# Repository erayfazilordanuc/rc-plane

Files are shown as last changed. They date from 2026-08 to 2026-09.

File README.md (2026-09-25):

# ESP32 RC Plane

<p align="center">
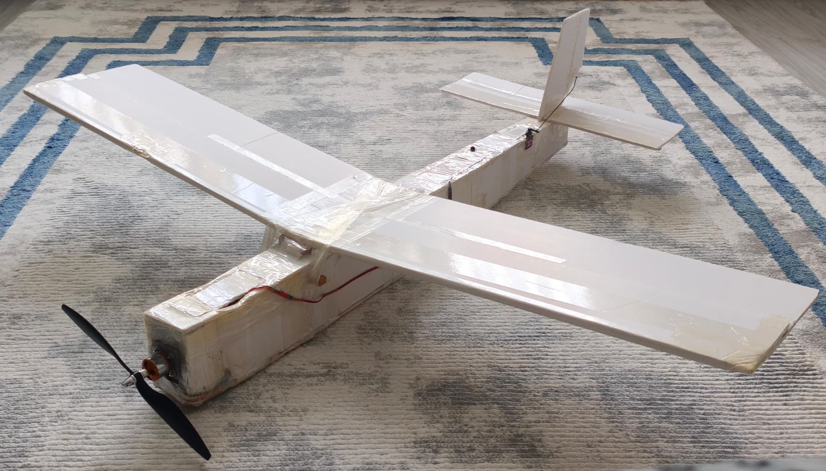
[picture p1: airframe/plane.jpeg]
The finished aircraft: white foam-board high-wing trainer with a green propeller, dihedral wing and conventional tail
  
</p>

A from-scratch radio control system and airframe. There is no hobby transmitter in this
project: an ESP32 ground station builds the RC frame itself from a phone's touch sticks,
and an ESP32 in the aircraft decodes it, drives the surfaces and reports back — over a
**redundant dual radio link** with failsafe logic on both ends. The airframe is a 1.4 m
foam-board trainer, designed on paper and cut by hand. It flies, but not for long: no launch
has lasted more than about ten seconds — [what the tests showed and what I got
wrong](#-flight-tests).

It started as a way around a ~5000 TL transmitter/receiver set. But once the ground station
*is* the transmitter, arming, failsafe and throttle limits become my problem rather than a
radio manufacturer's — so the interesting part is not that a servo moves, it is everything
that happens when the link degrades.

* **Two independent radios, one code path** — nRF24L01+ and ESP-NOW carry the same frame;
  either alone can fly the aircraft.
* **Safety enforced on both boards** — arm interlock, two-stage throttle ceiling, 500 ms
  failsafe, relink hysteresis, browser watchdog.
* **Phone as transmitter** — WebSocket touch gimbals with no app and no internet, servo
  calibration over the air, stored in the aircraft's flash.
* **Tested without hardware** — a Node harness checks the UI's maths against the firmware
  at 42 000 points before anything is flashed.

<p align="center">
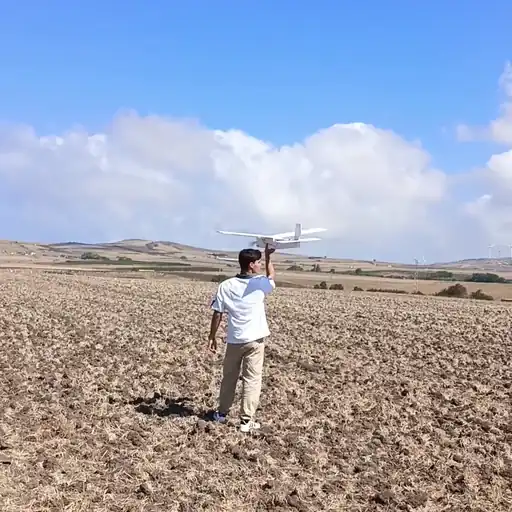
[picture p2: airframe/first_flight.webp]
Hand launch on a ploughed field: the aircraft leaves the hand under power, climbs away and flies across the field
  
  <br><sub>First field test, 21 September 2026 — hand launch and the first seconds of the flight.</sub>
</p>

## 📐 Mechanics

<p align="center">
  Airframe top, side and front views with dimensions: 1400 mm span, 200 mm chord, 1050 mm fuselage, CG 48 mm behind the leading edge
</p>

| | |
|---|---|
| **Construction** | 5 mm foam board, wooden spar, KFm-2 stepped airfoil, tape hinges |
| **Wing** | 1400 mm span, 200 mm constant chord, 28 dm², high wing, +1.4° incidence |
| **Control** | 3 channels — throttle, elevator, rudder; roll from rudder via 10° dihedral |
| **Tail** | 400 × 150 mm stabiliser (Vh 0.70), 180 mm fin (Vv 0.036) |
| **CG** | 278 mm from the firewall (measured): 48 mm behind the leading edge (24 %), just ahead of the spar |
| **Power** | A2212 1000 KV, 10×4.5 prop, 30 A ESC, 3S 2200 mAh 30C |
| **Weight** | 1106 g ready to fly, 39.5 g/dm² wing loading, thrust/weight ≈ 0.83 by eCalc (not measured) |

Tail volumes and CG are calculated, not guessed — thrust at flight speed was not, and that
is what the [flight tests](#-flight-tests) caught. Crashes are designed to be
cheap: the wing sits on **two dowels and rubber bands**, so a hard landing pops it off
instead of tearing the fuselage, and there is **no landing gear** — hand launch, belly
landing, sacrificial strip under the nose. The firewall and the ground station enclosure
are 3D-printed ([`cad/print_files/`](cad/print_files/)).

Every decision, the cut list, the weight budget and how the built aircraft differs from the
original plan: **[docs/AIRFRAME.md](docs/AIRFRAME.md)** (Turkish).

## 🔌 Electronics

```
┌──────────────────────────────┐            ┌──────────────────────────────┐
│  GROUND STATION (TX)         │            │  AIRCRAFT (RX)               │
│  WiFi AP ──► phone web UI    │  RcPacket  │  paketIsle()                 │
│  192.168.4.1   ┌──────────┐  │ ══ 50 Hz ═►│  ├─ verify (magic + CRC)     │
│                │ nRF24L01 │──┼─ 2.508 GHz │  ├─ arm interlock            │
│                └──────────┘  │            │  ├─ failsafe                 │
│                ┌──────────┐  │            │  └─ LEDC ──► ESC + 2 servos  │
│                │  ESP-NOW │──┼─ 2.412 GHz │                              │
│                └──────────┘  │◄═ telemetry│  RcTelemetry (8 B)           │
└──────────────────────────────┘            └──────────────────────────────┘
```

| | nRF24L01+ PA/LNA | ESP-NOW |
|---|---|---|
| Hardware | Separate module on VSPI, SMA antenna, `PA_HIGH` | **None** — the ESP32's own WiFi radio |
| Frequency | 2.508 GHz (channel 108) | 2.412 GHz (WiFi channel 1) |
| Addressing | `"RCP01"` pipe | Broadcast — no MAC pairing |
| Telemetry | ACK payload | Separate broadcast frame |

The 96 MHz gap is deliberate, so the access point cannot desensitise the nRF24. The
redundancy earned its place during bring-up: the nRF24 path was dead for a while (brown-out
on transmit, and a clone chip silently refusing 250 kbps) and ESP-NOW kept the aircraft
controllable while that was diagnosed.

### Ground station

<table>
<tr>
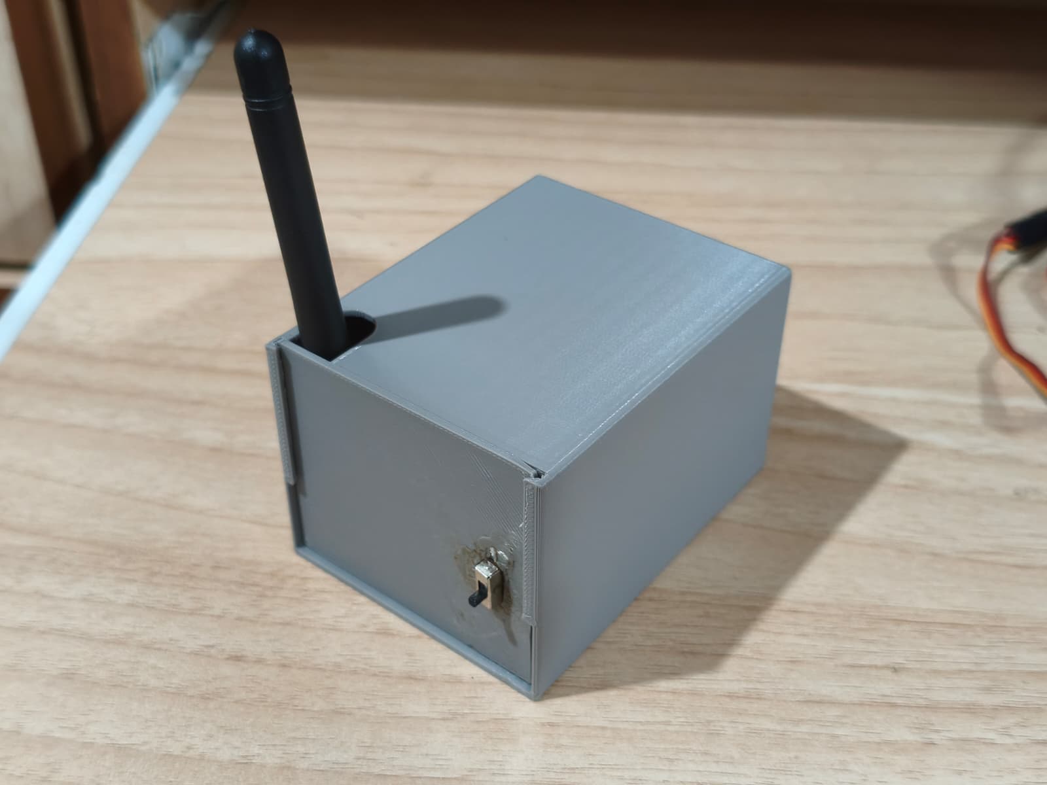
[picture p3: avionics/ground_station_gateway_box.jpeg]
Closed ground station: 3D-printed enclosure with antenna pass-through and power switch
<td width="50%"></td>
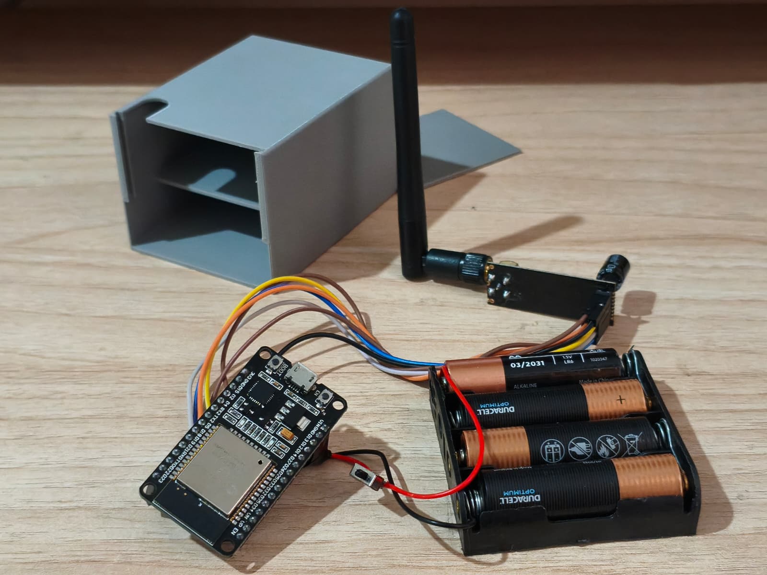
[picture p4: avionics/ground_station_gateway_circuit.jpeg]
Ground station opened up: ESP32-WROOM-32, nRF24L01+ PA/LNA with an SMA antenna, battery pack with a switch, next to its 3D-printed housing
<td width="50%"></td>
</tr>
</table>

The handheld transmitter: an ESP32-WROOM-32 and the nRF24 in a 3D-printed, 18650-powered
box. Runs the WiFi access point, the web server and the 50 Hz radio frame at once — the
dual core keeps HTTP work from stalling the frame. This board *is* the transmitter.

<p align="center">
  Ground station wiring diagram: nRF24L01+ on D23 MOSI, D19 MISO, D18 SCK, D5 CSN, D4 CE, 3V3 and GND with a capacitor at the module
</p>

Radio pins: SCK 18, MISO 19, MOSI 23, CSN 5, CE 4 — the same map as the aircraft, so a wiring
fix on one board is a wiring fix on the other.

### Avionics

<table>
<tr>
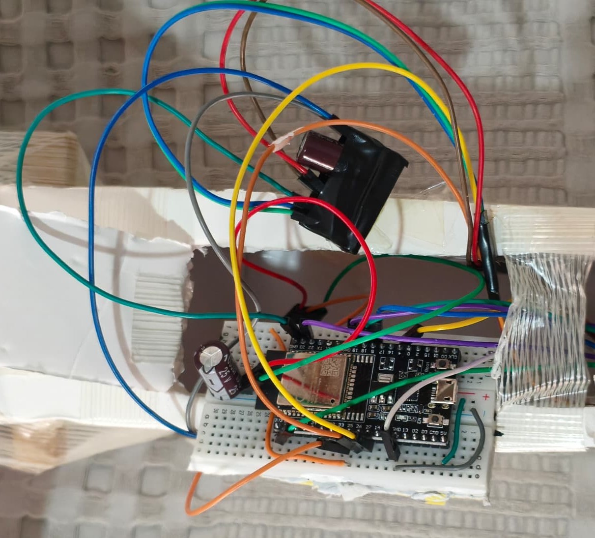
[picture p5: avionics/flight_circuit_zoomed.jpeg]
Electronics bay from above, installed in the fuselage: ESP32 DevKitC on a breadboard, nRF24 module wrapped in tape with its capacitor, wiring running out to the servos
<td width="50%"></td>
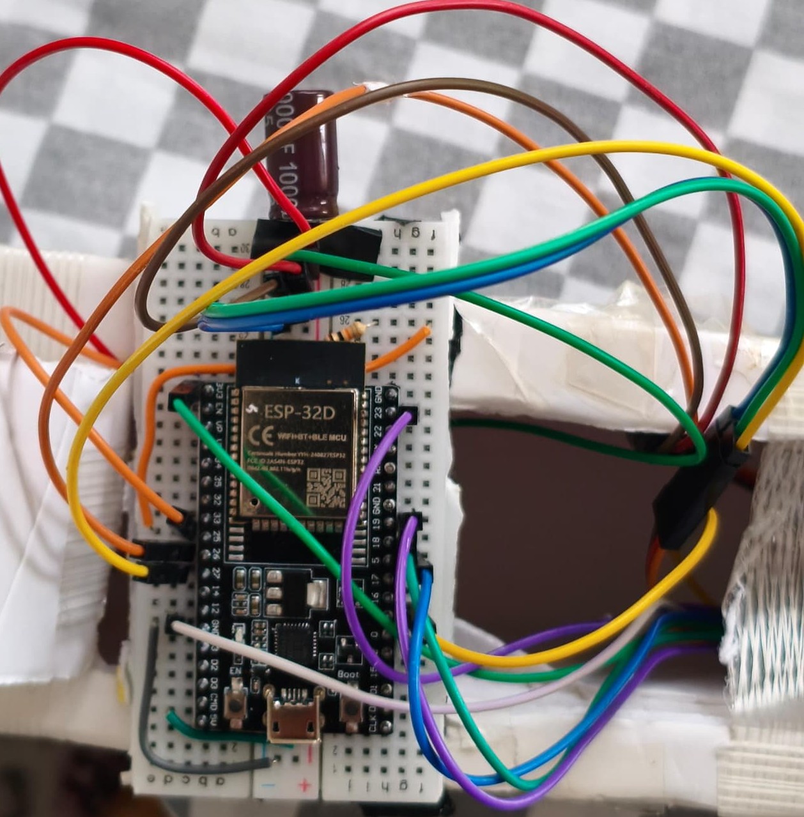
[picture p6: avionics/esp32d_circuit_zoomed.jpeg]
Close-up of the flight controller: ESP32-32D DevKitC on a breadboard with the bulk capacitor and jumper wires to the radio, ESC and servos
<td width="50%"></td>
</tr>
</table>

The flight controller: ESP32 DevKitC (WROOM-32D) inside the fuselage. Listens on both
radios, validates every frame, applies the stored calibration and drives the ESC and two
servos. Owns the failsafe, the arm lock and its own throttle ceiling, and sends telemetry
back.

**Power.** 3S LiPo → 30 A ESC → A2212, ≈ 15 A / 160 W at full throttle by eCalc. Moving the
servos used to crash the flight controller — first on the ESP32-C3 prototype, and again
after the move to the DevKitC. The cause was supply, not code: a 9 g servo pulls ~700 mA on
a step input, and the ESC's linear BEC, dropping 12 V to 5 V, could not hold the rail.
The fix was to disable that BEC and feed the board and servos from a **separate
5 V / 3 A UBEC** with a bulk capacitor across the rail; the crashes stopped. The boot log
prints the reset reason, so a returning `BROWNOUT` cannot hide.

<p align="center">
  Aircraft wiring diagram: ESC on GPIO25 with a 10k pull-down, elevator servo on GPIO26, rudder servo on GPIO27 through a servo rail; a separate 5 V UBEC feeds the rail and board with the ESC's BEC disabled; nRF24 on VSPI with a capacitor
</p>

| Function | GPIO |
|---|---|
| ESC signal | 25 *(10 k to GND)* |
| Elevator / Rudder | 26 / 27 |
| nRF24 SCK / MISO / MOSI | 18 / 19 / 23 |
| nRF24 CSN / CE | 5 / 4 |

Strapping pins (0, 2, 12, 15), the boot-pulsing GPIO 14 and the flash pins (6–11) are all
avoided; the 10 k keeps the ESC line quiet while the board boots. GPIO 32/33 carry mirrored
aileron outputs for a future 4-channel wing.

> ⚠️ **nRF24: 3.3 V only, and a 10–100 µF capacitor right at the module pins.** Without it
> the module browns out on transmit and `radio.begin()` succeeds only sometimes — the most
> misleading failure in this build. The firmware counts every radio recovery, so a
> brown-out cannot hide.

Cable-colour wiring tables: each firmware's `docs/kablolama.html` and
**[docs/RF_PROTOCOL.md](docs/RF_PROTOCOL.md)**. Diagrams are generated by
[`docs/diagrams/generate.py`](docs/diagrams/generate.py).

<details>
<summary>Earlier prototype: ESP32-C3 SuperMini on the bench</summary>
<br>
<p align="center">
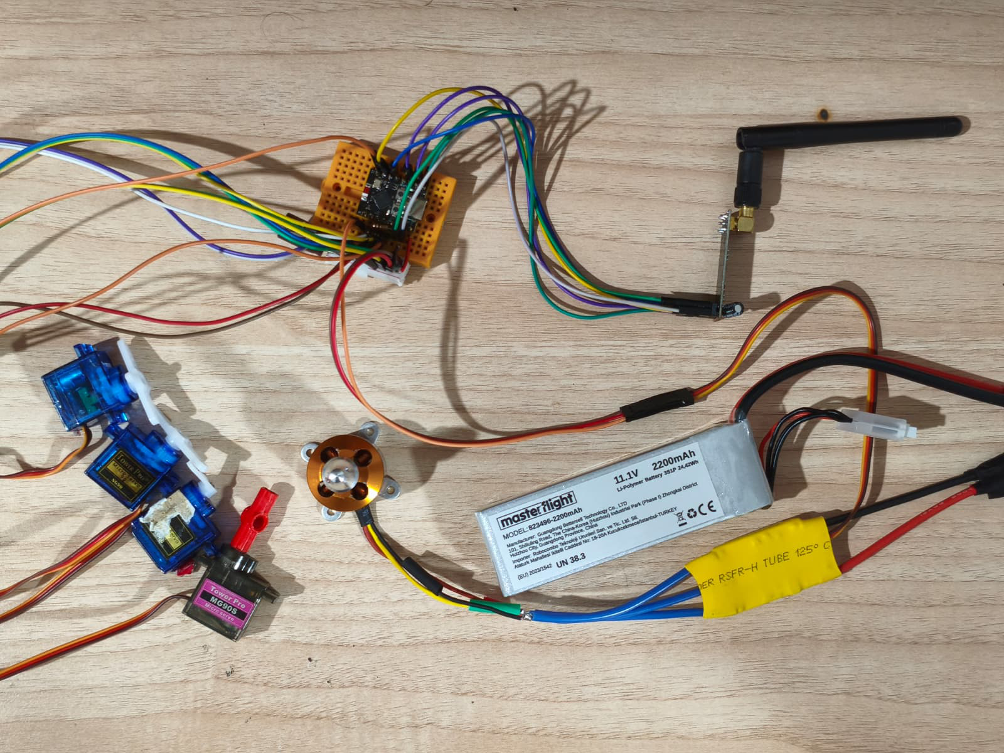
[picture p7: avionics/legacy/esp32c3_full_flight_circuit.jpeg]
Bench prototype: ESP32-C3 SuperMini on a mini breadboard, nRF24L01+ with antenna, 3S LiPo, ESC, A2212 motor and servos laid out on a desk
  
</p>
</details>

## 💻 Software

Two PlatformIO firmwares sharing one byte-identical protocol header (12-byte `RcPacket`,
CRC-8 on top of the nRF24's CRC-16, version nibble so mismatched firmware cannot half-work).

<p align="center">
  <picture>
    <source media="(prefers-color-scheme: dark)" srcset="docs/images/ui_3ch_dark.jpg">
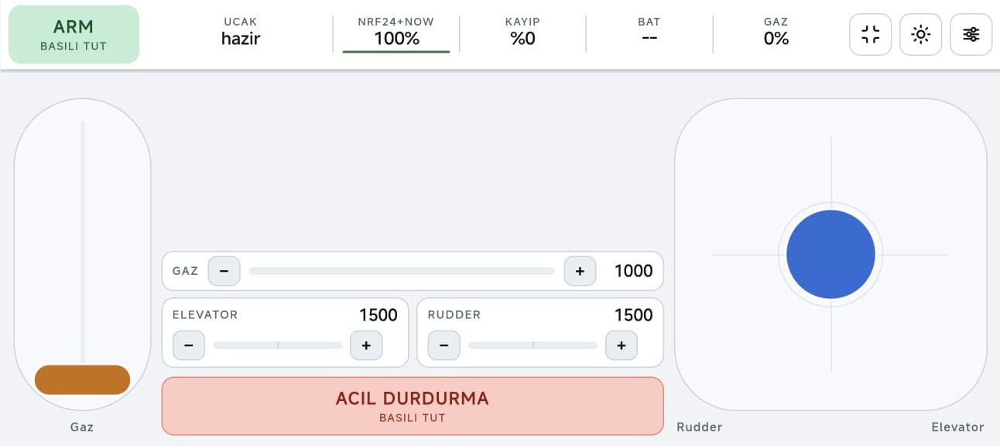
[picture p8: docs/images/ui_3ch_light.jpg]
Flight screen on a phone, 3 CH layout: throttle-only slot on the left, rudder and elevator gimbal on the right, ARM button and link, loss, battery and throttle readouts across the top, trim rockers and a hold-to-stop emergency button in the middle
    
  </picture>
  <br><sub>3 CH layout on the phone — aircraft ready, both radios up (<code>NRF24+NOW 100%</code>), no packet loss.</sub>
</p>

<details>
<summary>4-channel layout and the settings screen</summary>
<br>
<p align="center">
  <picture>
    <source media="(prefers-color-scheme: dark)" srcset="docs/images/ui_4ch_dark.jpg">
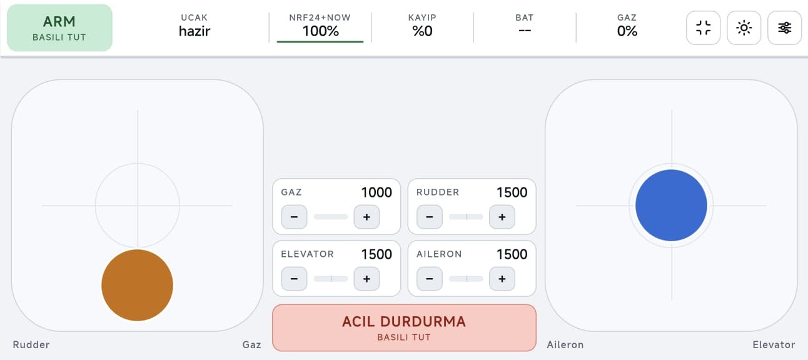
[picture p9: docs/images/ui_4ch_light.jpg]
Flight screen in 4-channel Mode 2: left gimbal rudder and throttle, right gimbal aileron and elevator, four trim rockers
    
  </picture>
  <br><sub>Mode 2 with ailerons enabled: two full gimbals, four trim rockers.</sub>
  <br><br>
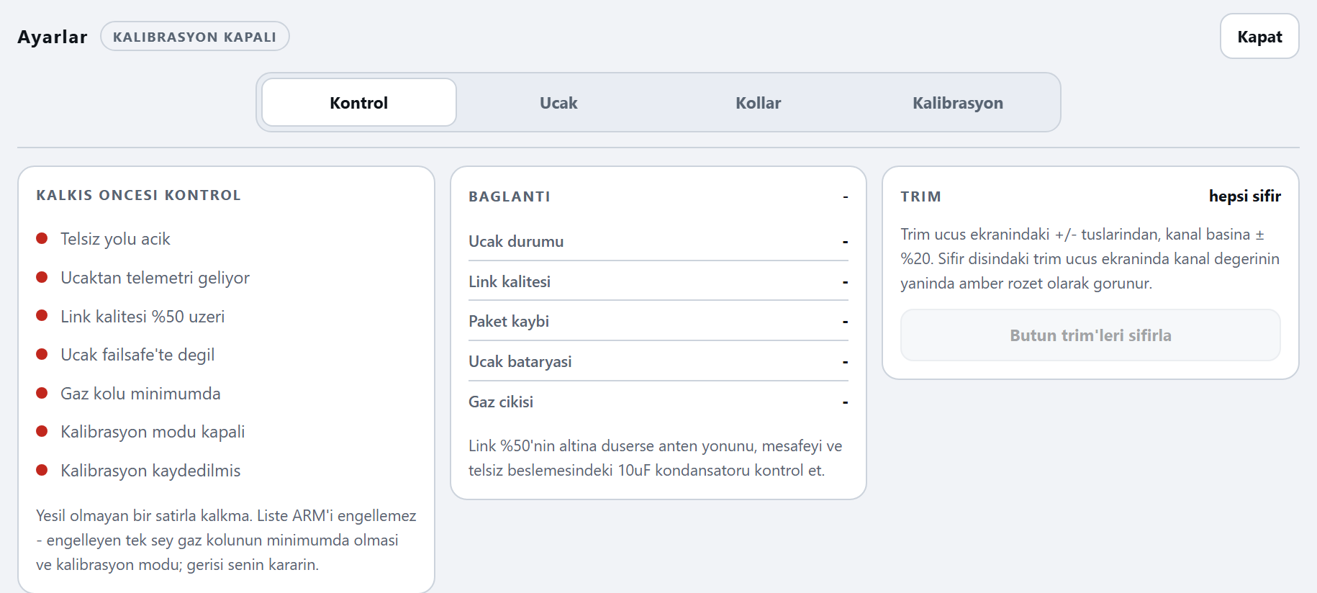
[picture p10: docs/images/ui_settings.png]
Settings screen: pre-flight checklist, link statistics and trim, with tabs for control, aircraft, sticks and calibration
  
  <br><sub>Settings, rendered from the firmware's own page with no aircraft connected — hence the red checklist.</sub>
</p>
</details>

### Safety — enforced independently on both boards

* **Arm interlock.** The aircraft boots locked and re-locks after every failsafe; it arms
  only after seeing `ARMED = 0` first, so a recovering link can never spin the motor.
* **Telemetry-gated arming.** The ground station will not arm without fresh telemetry —
  "controller says ARMED, aircraft never heard it" cannot happen.
* **Two-stage throttle ceiling.** Both sides clip against their own stored limit; the lower
  one wins. Set from the UI, no recompiling.
* **Failsafe.** 500 ms without a valid packet → ESC stop pulse, surfaces to *calibrated*
  neutral, arm dropped. Leaving it takes 10 consecutive good packets, so a twitching link
  doesn't stutter the motor.
* **Browser watchdog.** The 20 Hz stick push is the watchdog feed: close the tab or walk out
  of WiFi range and the ground station disarms within 1 s.
* **Duplicate suppression.** Both radios feed one `paketIsle()`; a packet seen twice is
  dropped by its `seq`, so outputs and telemetry are never doubled and the rules cannot drift
  apart between paths.

### Engineering notes

* **Direct LEDC servo output, no `ESP32Servo`** — microseconds end to end, same unit as the
  wire protocol. Runs at 14-bit resolution (~1.22 µs) because the C3 it started on silently
  fails at the 16 bits most examples use.
* **Non-blocking transmit** — `startWrite()` plus STATUS polling instead of `radio.write()`,
  which burns ~12 ms of the 20 ms frame when the link drops.
* **Broadcast telemetry, measured** — unicast gave `ack=0 / nack=57` and then
  `ESP_ERR_ESPNOW_NO_MEM`, because the aircraft is not associated with the AP. Broadcast
  needs no ACK; the payload carries its own magic byte and CRC.
* **Dependency-free WebSocket server** (`mini_ws.h`, SHA-1 and base64 included) —
  `WebServer` closes every connection, which made 20 Hz sticks jitter. Sends are gated by a
  zero-timeout `select()` so the flight loop never waits on a stalled socket.
* **Over-the-air servo calibration in NVS** — direction, sub-trim and per-side endpoints,
  retransmitted until acknowledged and read back from the aircraft, so the screen shows what
  was *applied*.
* **Honest sticks** — throttle engages only from the knob (no jumps), a finger sliding off
  the well freezes the value instead of tracking the edge, and every colour pair clears WCAG
  AAA for direct sun. USB gamepads work via the Gamepad API.
* **Self-healing radio** — `radio.begin()` retries every 3 s from a live register read, so a
  reseated wire recovers without a reset.

### Testing & diagnostics

```bash
cd firmware && node tools/run_all.mjs                       # UI harness, no hardware
cd controller_software && pio run -e rfdiag -t upload -t monitor   # raw-SPI nRF24 diagnosis
cd ../flight_software  && pio run -e bench  -t upload -t monitor   # servos/ESC from serial, no radio
```

The harness reads the firmware sources directly: stick maths, UI vs firmware throttle
formula at 42 000 points (the ARM threshold depends on it), the page's JavaScript against a
fake DOM, WCAG contrast in both themes, every `#id` present. `rfdiag` bypasses RF24 and
brute-forces all 12 pin-order combinations to find swapped wires.
[`sim_middleware`](firmware/sim_middleware/) is meant to turn the phone UI into a vJoy joystick
for simulator practice with the same controls — written, not yet tested against a simulator.

## Getting Started

**Needs:** [PlatformIO](https://platformio.org/) (RF24 is pulled automatically). Optional:
Node 24+ and Python 3.11 for the test harness.

```bash
git clone https://github.com/erayfazilordanuc/rc-plane.git
cd rc-plane/firmware/flight_software     && pio run -t upload -t monitor   # aircraft
cd ../controller_software                && pio run -t upload -t monitor   # ground station
```

Both `platformio.ini` files pin their serial port (`COM5` ground station, `COM6` aircraft)
because the two USB bridges look alike and PlatformIO would otherwise flash the wrong board.
Check yours with `pio device list`, one board at a time.

1. Power the ground station, join **`RC-Plane-TX`** / `rcplane1234` from a phone and open
   **`http://192.168.4.1`**.
2. Pick a layout — **Mode 1**, **Mode 2** (default) or **3 CH**. Elevator and rudder spring
   back; throttle stays put like a ratcheted stick.
3. **Settings → calibration:** set direction, neutral and endpoints per surface, sweep,
   **save to the aircraft**.
4. The pre-flight checklist shows exactly what is blocking ARM. **Remove the propeller for
   every bench test.**

Bench keys: `W`/`S` throttle, arrows elevator, `A`/`D` rudder, `Space` emergency stop,
`X` throttle cut.

```
airframe/  avionics/  cad/print_files/   photos, printable STLs
docs/       RF_PROTOCOL.md · AIRFRAME.md · ROADMAP.md (Turkish) · diagrams/ · images/
firmware/   controller_software/ · flight_software/ · tools/ · sim_middleware/
```

Per-firmware READMEs: **[ground station](firmware/controller_software/)** ·
**[aircraft](firmware/flight_software/)**. Deep-dives in `docs/` and source comments are in
Turkish.

## 🧪 Flight Tests

**What happened.** Hand launches from a ploughed field, first on **21 September 2026**, then
in a later session. The radio side worked every time; the airframe did not stay up. Every
launch was at full stick with default settings and a calibrated ESC — in the firmware that is
a 2000 µs pulse with nothing else limiting it (`gazUs()` on the ground station, `escYaz()`
on the aircraft).

| Launch | What the video shows (frame-counted) |
|---|---|
| Best, 21 Sep | Leaves the hand, climbs a little, then loses height slowly and cannot be held up — about ten seconds (clip at the top). The pilot's read: wind helped |
| Soft, nose-high | Released slow with the nose up, drops a wing, on the ground **1.2 s** after release |
| Lobbed upward | Thrown steeply up by the pilot, phone in the other hand; climbs a few metres, settles back, on the ground **~4.5 s** after release |

<p align="center">
  Two charts from a simple performance model at full throttle, for three possible static thrusts: about 912 g from eCalc, 650 g and 450 g. Left: thrust against drag versus airspeed; stall is about 8.5 m/s and at 450 g thrust never exceeds drag. Right: simulated hand launch from 2 m at 8.5 m/s; with a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
</p>

**What the model says.** A point-mass model, not a measurement —
[`flight_model.py`](docs/diagrams/flight_model.py), assumptions under the chart. Static thrust
comes from an eCalc run of this drive (below); how it falls off with speed comes from
Staples' propeller equation.

| | |
|---|---|
| Stall speed | ≈ 8.5 m/s |
| Minimum-drag speed | ≈ 8.4 m/s — the same as stall |
| Pitch speed, 10×4.5 | ≈ 16 m/s; at 10 m/s the prop gives 38 % of its static thrust |
| Full throttle, ≈ 912 g static (eCalc) | Level flight at 8.5–13.1 m/s, best climb ≈ 2.4 m/s |
| Static thrust below which height cannot be held | ≈ 440–500 g (thrust/weight 0.4–0.45) |

**Cross-check: eCalc.** I ran the same drive in [eCalc propCalc](https://www.ecalc.ch/)
(A2212 1000 KV, 10×4.5, 3S 2200 mAh 30C, 1105 g):

| | eCalc |
|---|---|
| Full throttle | 15.1 A, 10.5 V, 161 W, 8 680 rpm — 6.9 C on the pack, motor 82.5 % efficient |
| Static thrust | ≈ 912 g, thrust/weight 0.83 |
| Pitch speed | 60 km/h (16.7 m/s) |
| Stall / level speed | 30 km/h (8.3 m/s) / 68 km/h (18.9 m/s) |
| Rate of climb | 4.5 m/s |
| Flight time | 7.4 min at full throttle, 10.6 min mixed |

eCalc agrees on stall and pitch speed and is more optimistic than my model about the rest
(4.5 against 2.4 m/s climb). The conclusion doesn't depend on which is right: on paper,
this drive climbs.

* **Paper and field disagree — that is the finding.** With ≈ 912 g static both models
  climb away at full throttle. The aircraft didn't. The model reproduces the slow sink
  only if the motor makes less than ~500 g static, or if the wing is flying past its stall,
  where drag is far beyond this model (attached flow would need CD0 ≈ 0.3).
* **Power or speed?** The sink happens at low speed: the aircraft never gets clear of stall
  speed. What holds it there is the open question — too little thrust to accelerate, or a
  wing held at too high an angle (nose-high release, up elevator) that drags too much to
  accelerate. One measurement separates them: static thrust around 800 g or more clears the
  power train; around 500 g or less convicts it.
* **No speed margin.** Minimum-drag speed sits on top of stall speed, so anything that slows
  the aircraft — a soft throw, a nose-high release, pulling elevator to stop a sink — raises
  drag and deepens the sink. A 7 m/s throw starts below stall.
* **Wind — the best flight may have been luck.** Launched into a headwind, the aircraft
  leaves the hand with the throw *plus* the wind as airspeed, and a gust adds more for a
  moment. With stall and minimum-drag speed on top of each other, a lull is enough to drop it
  back into the sink. What wind can't do: a steady wind doesn't change airspeed once the
  aircraft is flying, and turning downwind costs groundspeed, not airspeed — only rising air
  holds a sinking aircraft up. Wind wasn't measured, so this stays a hypothesis.
* **It cannot glide out of trouble.** From 2 m with the motor off the model is on the ground
  in 1.6 s. Ten seconds in the air means the motor was pulling — without enough margin.

**What I got wrong.**
* Designed with static numbers — thrust/weight, tail volumes, CG — and never plotted thrust
  against drag at flight speed.
* Never measured the thrust. The 0.83 thrust/weight is eCalc's estimate, and "it rolls
  forward on the ground" only shows that thrust beats ground friction — a fraction of the
  weight.
* Weight grew 13 % (976 → 1106 g), wing loading 35 → 39.5 g/dm²; the margin was not
  re-checked.
* Launches were soft or nose-high, one of them one-handed.
* The docs recommend a 70–80 % throttle limit for first flights — wrong for this margin
  (the tests were flown at 100 %).
* Flew without data: no flight log, no fixed camera, no measured thrust, no wind reading.
  Every number above
  is a model until one of those exists.

**Proposed fixes, checked against the model.** An outside review of the first flights
suggested these:

| Proposal | Verdict |
|---|---|
| 9×6 prop instead of 10×4.5 | **Helps** — pitch speed 16 → 22 m/s, best climb 2.4 → 2.7 m/s (rpm assumed — to be run in eCalc). Check current draw |
| 1300–1500 mAh battery instead of 2200 | Small — about −80 g, stall −4 %; CG must be re-balanced |
| Rebuild at 750–800 g (bare foam or XPS) | **Biggest lever** — stall 7.0–7.2 m/s, wing loading 27–29 g/dm² |
| Clark Y / NACA 4412 instead of KFm-2 | Plausible, less drag; a new wing, so after the cheap fixes |
| Fin +15–20 % against spiral dives | **Not supported.** Vv 0.036 is within the usual 0.02–0.05. A bigger fin makes spiral divergence *more* likely, not less; strong dihedral with a small fin leans toward Dutch roll. Needs a stability analysis |
| Expo / deadband on the touch rudder | Expo is already there (25 % default); a deadband is not — cheap to add |

## Next Steps

### Without new parts

In this order — each result goes back into the model and this README.

1. **Static thrust** — tie the tail to a luggage scale anchored to a post, aircraft on a
   smooth floor, full throttle for a few seconds. Or stand it tail-down on a kitchen scale,
   held upright without pressing: weight minus reading = thrust. eCalc says ≈ 912 g.
2. **RPM and battery sag** — record the prop with [phyphox](https://phyphox.org/) (audio
   spectrum); RPM = blade-pass frequency × 30 for a two-blade prop, the model assumes
   ≈ 8 680. If a multimeter is at hand, read pack voltage at full throttle.
3. **Prop check** — size lettering and the curved face toward the front, nothing rubbing,
   air blown backwards. A prop mounted backwards loses much of its thrust.
4. **Launch drill** — full throttle before release, into the wind, wings level, nose on the
   horizon, a firm throw straight ahead. One person throws, the other flies. Don't pull while it sinks; let
   it gain speed.
5. **Fixed camera and wind** — tripod, side-on, 60 fps, two markers a known distance apart,
   a tape streamer on a stick in frame. [Tracker](https://physlets.org/tracker/) turns the clip
   into groundspeed and sink rate; with the wind, that is airspeed — the first measured numbers
   for the model. For 21 September, look up the hourly wind at the field in
   [Open-Meteo's historical data](https://open-meteo.com/en/docs/historical-weather-api).
6. **XFLR5** — model wing and tail in [XFLR5](http://www.xflr5.tech/) at Re ≈ 130 000: real
   polars instead of assumed drag and CL max, the static margin, and the dynamic modes
   (spiral, Dutch roll) that settle the fin question.
7. **eCalc, 9×6** — the 10×4.5 run is above; run 9×6 on the same drive for thrust, current
   and pitch speed before buying one.
8. **Simulator** — first check that [`sim_middleware`](firmware/sim_middleware/) works at all
   (untested). Then build this aircraft in RealFlight (1106 g, 1.4 m, 28 dm², 10×4.5,
   1000 KV) and practise launches.
9. **Flight log** — the ground station writes every frame to CSV, downloadable from the UI
   ([ROADMAP §4](docs/ROADMAP.md)).
10. **Rudder deadband** in the touch UI.

### Needs parts

* **9×6 prop** — more thrust at flying speed whatever step 1 shows.
* **Soldered board** — the electronics still sit on a breadboard inside the fuselage.
* **Battery telemetry** — `bataryaOku()` returns 0 today; needs a divider on an ADC1 pin.
* **Physical sticks** and **range testing** under real separation.
* **A lighter airframe** if the prop change is not enough.

Longer plan — link authentication, IMU stabilisation: **[docs/ROADMAP.md](docs/ROADMAP.md)**
(Turkish).

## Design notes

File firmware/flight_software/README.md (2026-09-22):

# Aircraft — `flight_software`

The airborne half of the RC Plane link. An **ESP32 DevKitC** (38-pin, ESP-WROOM-32 / 32D) listens on two radios at
once, validates every frame, runs it through a stored calibration curve, and drives the ESC
and two servos — with its own failsafe logic that does not trust the ground station.

**Three channels: throttle, elevator, rudder.** No ailerons — roll comes from rudder via
wing polyhedral, the classic 3-channel trainer layout. Which stick carries which surface is
a ground-station setting and does not reach this board: it always receives the same three
channels in the same order.

```
   nRF24 2.508 GHz  ═╗
                     ╠═► paketIsle() ─► magic + CRC-8 + version
   ESP-NOW 2.412 GHz ═╝        │        duplicate suppression
                               │        arm interlock
                               │        failsafe
                               ▼
                        calibration curve  ──► LEDC ──► ESC + 2 servos
                               │
                               └──► telemetry + calibration reports ──► ground
```

Either radio alone flies the aircraft. Both paths land in the same `paketIsle()`, so
validation, the arm lock and failsafe are defined exactly once.

---

## Wiring

Full diagram: [`docs/kablolama.html`](docs/kablolama.html) — open it in a browser.

| Function | GPIO | Note |
|---|---|---|
| **ESC signal** | **25** | 10 k from signal to GND — the pin floats during boot, the resistor keeps garbage out of the ESC |
| **Elevator servo** | **26** | |
| **Rudder servo** | **27** | |
| nRF24 SCK | 18 | VSPI |
| nRF24 MISO | 19 | VSPI |
| nRF24 MOSI | 23 | VSPI |
| nRF24 CSN | 5 | |
| nRF24 CE | 4 | |
| nRF24 VCC | 3V3 | top-left pin on the 38-pin board — **never 5 V** |

The radio uses the same five GPIOs as the ground station. GPIO 32/33 still carry the
mirrored aileron outputs in firmware; nothing is connected to them on this 3-channel airframe.

Avoided: **GPIO 0, 2, 12, 15** (strapping — a pulldown on GPIO0 drops the board into the
bootloader on every power-up, which is why the ESC moved off it), **14** (PWMs during boot),
**6–11** (internal flash, silkscreened `D0–D3`, `CMD`, `CLK` — `D2` is *not* GPIO2) and
**1/3** (UART0).

`SPI.begin(sck, miso, mosi, ss)` still names the pins explicitly, so a library that grabs SPI
first cannot move the radio. SPI runs at **4 MHz** — the same value the ground station
settled on, so the two cannot drift apart.

**Power.** The board and both servos run from a **separate 5 V / 3 A UBEC** on the flight
battery; the ESC's own linear BEC is disabled. A capacitor sits across 5 V–GND on that rail.
nRF24 on 3.3 V, with a 10 µF capacitor at its pins. Grounds common.

The boot log prints the reset reason. If you see `BROWNOUT` — especially *again* after
powering the motor — the problem is supply, not software: check the capacitor on the 5 V
rail and the ground first, then the UBEC's current rating and the wire gauge feeding it.

---

## Outputs

All three outputs are driven by the chip's LEDC peripheral directly. `ESP32Servo` is not
used, for two concrete reasons: its pin allowlist rejects GPIO0, and its degree↔µs
conversion shifted the neutral point. Writing duty directly means the firmware speaks the
same unit as the wire protocol — microseconds, end to end, no conversion anywhere.

> **The 14-bit C3 trap.** This firmware started on an ESP32-C3, whose LEDC timer maxes out at
> 14 bits, while nearly every example online uses 16 — valid on the classic ESP32. On the C3
> that made `ledcSetup()` silently return 0: no PWM at all, 0 V on the pin. Resolution stays
> at 14 bits so the code keeps working if the board ever goes back, and setup still checks
> the return value and shouts if it is zero. 14 bits @ 50 Hz gives ~1.22 µs resolution.
>
> On the classic ESP32 LEDC channels share timers in pairs (0–1, 2–3, 4–5). Every output
> here runs at 50 Hz / 14 bit, so sharing is harmless — an output at a different frequency
> needs its own pair, or `ledcSetup()` silently retunes its neighbour.

---

## Calibration

Servo direction, sub-trim and endpoints are **not** compile-time constants. They live in
this board's NVS (`rcplane`), set over the air from the ground station's settings screen.

That placement is deliberate: endpoints belong to the airframe's linkage geometry, not to
the pilot. They survive a reset, they can be changed with the receiver buried in a fuselage
and no USB attached, and — the part that actually matters — **failsafe neutral becomes the
calibrated neutral** rather than a hardcoded 1500 µs. If a linkage sits off-centre, so would
a hardcoded failsafe.

### The mapping

Standard **end point / travel adjust** behaviour, with independent scaling either side of
neutral:

```
input > 1500  →  scaled into  midUs .. maxUs
input < 1500  →  scaled into  minUs .. midUs
```

You can give one direction 100 % travel and the other 70 %; mechanical linkages are never
symmetric. Reversal happens *before* scaling, mirrored around neutral, so flipping direction
does not swap your endpoints.

Throttle reinterprets the same three fields: `minUs` is the ESC stop pulse, `maxUs` is full
throttle, and `midUs` is this aircraft's **own throttle ceiling** — independent of the
transmitter's limit, lower of the two wins.

### Why calibration cannot hurt the aircraft

| Guard | Where |
|---|---|
| Entering calibration is refused while armed | `RC_CFG_ENTER` |
| Arming is impossible while in calibration | `armed = ... && !kalibModu` |
| ESC pinned to its stop pulse for the whole mode | `escYaz()` |
| `TEST` and `SWEEP` never apply to the throttle output | `konfigIsle()` |
| Every write clamped to 900–2100 µs | `cikisYaz()` → `rcClampHard()` |
| Ordering and ≥50 µs of travel enforced before accepting | `ayarGecerli()` |
| `TEST` returns to neutral after 4 s | `kalibTick()` |
| Link loss exits calibration | `failsafeUygula()` |
| Corrupt NVS record falls back to factory values | `ayarYukle()` — signature + validation |

The `TEST` timeout matters more than it looks: a servo parked against a linkage stop draws
current and heats up. Every new `TEST` resets the timer, so the servo holds wherever you
want it while you drag a slider, and lets go when you walk away.

`SWEEP` runs a triangle wave min→max→min over 3 s, three times, then re-centres — enough to
hear a binding linkage before it strips a gear in the air.

**Throttle has no reverse.** Reversed throttle means full power with the stick down; the
setting that is useful on a control surface is a failure mode on a motor.

### ESC throttle range

An uncalibrated ESC can still read 1200 µs as stop — the usual cause of *"throttle is going
out but the motor won't turn"*. Two ways to teach it:

* **Serial** — press `k` within 5 s of boot, then confirm each step with `e`. The window
  opens on every boot (the classic ESP32 cannot tell whether USB is attached, unlike the C3's
  native USB), so a stray byte on the UART must never be enough to reach full throttle.
* **Over the air** — the settings screen, behind a prop-removed checkbox. This board also
  requires the `RC_CFGF_PROP_OFF` bit, calibration mode, and disarmed, then drops back to
  stop by itself after 30 s if step 2 never arrives.

Both routines deliberately exceed the throttle ceiling, which is why neither is reachable
from flight code. **Remove the propeller.**

---

## Failsafe and the arm chain

| Condition | Result |
|---|---|
| No valid frame for 500 ms | ESC to stop, surfaces to **calibrated** neutral, disarmed, arm lock re-armed |
| Bad magic / CRC / protocol version | Frame dropped silently, consecutive-valid counter reset |
| Link returns | **10 consecutive** valid frames required before leaving failsafe |
| Boot, and after every failsafe | **Arm-locked** — will not arm until it has seen a frame with `ARMED = 0` |

The arm lock is the piece worth explaining. A recovering link must never spin the motor on
its own, so the lock only releases when the ground station explicitly reports disarmed —
meaning the operator has to cycle DISARM → ARM by hand.

The relink hysteresis exists because recovering on a single frame made the motor stutter
every time the link twitched.

> **Ground station state ≠ aircraft state.** The interface shows both. If the transmitter
> says ARMED while this board says DISARM, the arm lock has not released — press DISARM and
> ARM again.

---

## Telemetry

An 8-byte frame carrying battery millivolts, packet loss, `rxHz`, and status bits (armed /
failsafe / calibration / unsaved-config). It rides the nRF24 ACK payload and goes out as an
ESP-NOW broadcast, **and refreshes every 100 ms independently of packet arrival**.

That independence is not decoration. The ground station refuses to arm without fresh
telemetry, and duplicate-suppression gaps would otherwise read as *"the aircraft is not
answering"*.

`rxHz` counts unique frames per second. Link quality as a percentage never answered "how
many frames actually arrived"; at 50 Hz you expect 50, and any shortfall is visible directly.

In calibration mode the same return path alternates telemetry with configuration reports,
cycling through all three outputs at about 5 Hz. Each report carries the value **actually
being written** to that output — so the settings screen shows what the aircraft applied, not
what was sent to it.

Battery measurement is stubbed at `0`, which the interface renders as `--`. Add a divider to
an **ADC1** pin (GPIO 32–39, e.g. 35 — ADC2 is unusable while ESP-NOW holds the radio) and
fill in `bataryaOku()`; the gauge starts working on its own.

---

## Build & flash

```bash
pio run -t upload -t monitor
```

`platformio.ini` pins **COM6** explicitly. That number belonged to the old C3's native USB;
the DevKitC enumerates through its USB bridge and may get another one — run
`pio device list` with only this board attached and update both environments. Without a
pinned port PlatformIO takes the first one it finds — COM5, the ground station — and flashes
the wrong board.

Roughly 58 % of the app partition, 13 % of RAM.

### Bench testing

```bash
pio run -e bench -t upload -t monitor    # no radio at all
pio run -t upload -t monitor             # back to flight firmware
```

[`hardware_test/servo_bench_ledc.cpp`](hardware_test/servo_bench_ledc.cpp) drives the
outputs from the serial port with no radio involved, which splits "is the software wrong" from
"is it power, ground or wiring". If the servos move here, the software and pin mapping are
fine.

It also carries two diagnostics for hand-soldered boards, where the silkscreen number and
the actual GPIO do not always agree:

* `t` — pulls every candidate pin to 3.3 V DC at once. Every wire you soldered should read
  3.3 V at its far end; 0 V means it is not on the board, or it is a cold joint.
* `p` — walks the candidates one at a time and prints which pin it is driving, so you can
  find which GPIO a mystery wire actually lands on.
* `v` — 50 % duty on the selected servo pin for 5 s. A normal servo pulse is 5–10 % duty and
  reads 0.16–0.33 V on a cheap multimeter, indistinguishable from nothing. 50 % reads
  ~1.65 V and leaves no doubt.

**Disconnect the ESC, servos and nRF24 for `t` and `p`, and power the board from USB** — they
drive plain 3.3 V DC, and pushing that into a line tied to 5 V damages the chip.

`hardware_test/hardware_test.ino` is an Arduino IDE archive of the same idea, kept only for
a quick try. Nothing builds it; the LEDC version above supersedes it.

### Reading the log

```
[RX] nrf=BAGLI now=BAGLI | DISARM rxarm=0 kilit=ACIK relink=0/10 |
     thr=1000<-1000(disarm) ele=1500->1500 rud=1500->1500 |
     50 paket, tekrar 50, kayip %0, bozuk 0 | tlm nrf=50/red0 now=50/hata0
```

| Field | Meaning |
|---|---|
| `rxarm` | The raw ARMED bit as received |
| `kilit` | Arm lock. `KAPALI` means ARMED is ignored no matter what arrives |
| `thr=A<-B(reason)` | A applied, B requested, and why it was clipped |
| `ele=A->B` | A received, B written after the calibration curve |
| `tekrar` | Copies arriving via the second radio — normal, not loss |

*"Throttle is going out but the motor won't turn"* with `thr=1000<-1600(disarm)` in the log
means the problem is the arm gate, not the transmitter.

`tekrar` sitting near the unique-frame count is what a healthy redundant link looks like:
every frame arrived twice, and the second copy was discarded before it touched an output.

---

## Layout

```
src/main.cpp                        radios, safety chain, calibration, LEDC outputs, NVS
include/rc_protocol.h                wire format — byte-identical copy in controller_software
hardware_test/servo_bench_ledc.cpp   bench test + solder diagnostics (separate environment)
hardware_test/hardware_test.ino      Arduino IDE archive, not built
docs/kablolama.html                  wiring diagram, open in a browser
```

Protocol details: [`docs/RF_PROTOCOL.md`](https://github.com/erayfazilordanuc/rc-plane/blob/main/docs/RF_PROTOCOL.md).

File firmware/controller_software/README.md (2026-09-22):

# Ground Station — `controller_software`

The transmitter half of the RC Plane link. An **ESP32-WROOM-32** raises its own WiFi
access point, serves a phone flight interface, and pushes a 10-byte RC frame to the
aircraft **50 times a second** over two independent radios.

There is no commercial transmitter in this project. This board *is* the transmitter.

```
        phone (browser)                    this board                        air
   ┌────────────────────────┐      ┌──────────────────────────┐
   │  two touch gimbals     │  WS  │  expo · dual rate · trim │   nRF24 2.508 GHz
   │  bottom corners        │ ═══► │  arm interlocks          │ ═══════════════════►
   │  sends on touch event  │ :81  │  50 Hz frame builder     │   ESP-NOW 2.412 GHz
   └────────────────────────┘      └──────────────────────────┘ ◄═══ telemetry ═════
      RC-Plane-TX / 192.168.4.1            ESP32-WROOM-32
```

---

## What it does

| | |
|---|---|
| **WiFi AP** | `RC-Plane-TX` / `rcplane1234`, channel 1, one client, `http://192.168.4.1` |
| **Interface** | Single page, ~39 KB, served straight from PROGMEM. No SD card, no upload step |
| **Uplink** | `RcPacket` (10 B) at 50 Hz over nRF24 **and** ESP-NOW simultaneously |
| **Downlink** | Telemetry (8 B) and calibration reports (13 B), from either radio |
| **Stored on board** | Pilot settings — stick mode, trim, expo, dual rate, throttle limit |

Protocol details live in [`docs/RF_PROTOCOL.md`](https://github.com/erayfazilordanuc/rc-plane/blob/main/docs/RF_PROTOCOL.md). The wire format
itself is in [`include/rc_protocol.h`](include/rc_protocol.h), which must stay **byte-identical**
to the copy in `flight_software`.

---

## Wiring

nRF24L01+ on VSPI. `SPI.begin()` names the pins explicitly — partly as documentation,
partly to override any library that grabbed SPI first.

| nRF24L01 | ESP32 | Wire colour |
|---|---|---|
| VCC | **3V3** — never 5 V | red |
| GND | GND | black |
| CE | GPIO4 | blue |
| CSN | GPIO5 | magenta |
| SCK | GPIO18 | orange |
| MOSI | GPIO23 | cyan |
| MISO | GPIO19 | green |
| IRQ | not connected | — |

SPI runs at **4 MHz**, not the library's 10 MHz default — dupont wire and breadboard are
not reliable at 10 MHz.

> **A 10–100 µF capacitor across VCC–GND, as close to the module pins as possible, is not
> optional.** The module draws a current spike on transmit; without the cap it browns out
> and `radio.begin()` succeeds only sometimes. That intermittency is the single most
> misleading failure in this build.
>
> The header is 2×4 with **GND on pin 1 and VCC on pin 2**. Being one row off reverses the
> supply and kills the module. Touch it after powering up — if it is warm, pull it.

---

## The interface

Designed as an instrument panel, not a web page. Landscape, gimbals in the **bottom
corners**, at least 140 dp on a side (`clamp(140px, min(34vw,46vh), 300px)`).

**Three stick layouts.** A 3-channel airframe has no ailerons, so one horizontal axis is
always spare — what changes between modes is *where* the spare axis sits. It is drawn
locked and greyed rather than left looking broken.

| | Left stick | Right stick |
|---|---|---|
| **Mode 1** | rudder + elevator | throttle |
| **Mode 2** *(default)* | rudder + throttle | elevator |
| **3 CH** | throttle only | rudder + elevator |

Mode 2 is the simulator and world standard. **3 CH** is the layout you get on a real radio
by assigning rudder to the aileron channel and gathering both surfaces on the right stick,
which leaves the left stick as a pure throttle lever — a common preference on 3-channel
trainers. The mode is stored on the board, so it survives a phone change.

Elevator and rudder spring back to centre on release. Throttle stays where you left it,
like a ratcheted stick.

### Anchored sticks: touching is not a command

The moment a finger lands, the stick's *current* value is anchored to that point. What moves
a channel is the motion **after** touchdown — where in the well you landed is irrelevant.

Absolute mapping came first, and it had two faults. The obvious one: grabbing a stick meant
hitting its exact centre, and missing made the stick **jump** to wherever the finger landed.
The one that matters in the air: a hand brushing the well threw a surface to full deflection
instantly.

Anchoring removes both. A knock only sets a reference point; nothing moves.

**Origin push** is the known trap of this model and its fix. With a fixed reference you could
not grab near the top of the well and keep pulling up, so full deflection was unreachable in
one gesture. When the limit is hit the *base value* shifts instead, keeping the finger
meaningful: full deflection is reachable from any grab point, and pulling back responds
**immediately** rather than sticking at saturation. The well border turns amber at full
deflection.

**Scale:** 100 px of finger travel is half a channel's width. Surfaces run centre-to-edge for
full deflection, throttle bottom-to-top for 0→100 % — the same total travel either way, like a
physical gimbal. Lifting and re-grabbing accumulates.

Multi-touch is per gimbal via pointer capture, so *released* and *dragged outside* never get
confused and both sticks work at once. A second finger in the same well is ignored.

### Guarding against knocks

A hand will hit the screen mid-flight. The decisions:

| Risk | Decision |
|---|---|
| A knock throws a surface | Anchored sticks — touching changes nothing |
| Palm and thumb in one well | Second `pointerId` in that well is ignored |
| Touch outside the wells | Drives no channel at all |
| ARM / emergency hit by accident | **Press-and-hold** (600 ms / 400 ms); sliding 44 px cancels |
| Settings opening over the sticks | AYAR is locked while armed |
| Back gesture, long-press menu | Swallowed (`popstate`, `contextmenu`) |
| Accidental reload | Browser confirms while armed (`beforeunload`) |
| System edge gesture reaching a stick | Wells sit 16 px in from the edge |
| URL bar and edge swipes | Fullscreen + landscape lock attempted on first touch |

Requiring a hold on the emergency stop is deliberate: a stray finger cutting the motor into a
forced landing costs far more than 400 ms does in a real emergency.

**Stick data is sent on the touch event itself**, not on a timer — 10 ms floor only so a
120 Hz digitiser cannot flood the socket, plus a 50 ms keepalive that doubles as the
watchdog feed. The interface adds no buffering of its own; end-to-end latency is
essentially the radio's own 20 ms frame.

Also on the flight screen: a pre-arm checklist that names whatever is blocking ARM, live
link / packet-loss / battery / throttle readouts, in-flight trim rockers, and a large
failsafe banner that never covers the sticks.

**Deliberately absent from the flight screen:** animation, transitions, gradients, shadows.
Every colour pair on it clears WCAG AAA against its background, so it stays readable in
direct sun. `navigator.vibrate()` marks arm, disarm and failsafe; a screen Wake Lock keeps
the display on, and pulling down the notification shade does not disturb a single channel.

A USB gamepad works too, through the Gamepad API. Keyboard, for bench work: `W`/`S`
throttle, arrows elevator, `A`/`D` rudder, `Space` emergency stop, `X` throttle cut.

---

## Safety

Every guard here is duplicated independently on the aircraft. Trusting one side alone means
a corrupted packet or a stale browser tab can spin a propeller.

| Condition | Result |
|---|---|
| Boot | Always disarmed |
| Throttle **output** above 1020 µs | ARM refused — checks the pulse, not the stick, so positive throttle trim cannot sneak past |
| No fresh telemetry from the aircraft | ARM refused, and auto-disarm after 1 s |
| Aircraft in calibration mode | ARM refused; auto-disarm if it enters one |
| Browser silent for 1 s | Auto-disarm, surfaces neutral |
| Disarmed | Throttle channel forced to 1000 µs on the wire |
| Emergency button / `Space` | Immediate disarm, all channels neutral |

`TEZGAH_MODU` (bench mode) relaxes only the telemetry requirement, for diagnosing a broken
downlink on the bench. **It ships as `false`.** When true it shouts about it in the boot log,
in every `[TX]` line, and across the top of the interface.

---

## Stick feel

Applied on this board, not in the browser, so a different phone cannot lose your trim.
Stored in NVS under `rctx`.

| Setting | Range | Default |
|---|---|---|
| Stick mode | 1 / 2 / 3 (3 CH) | 2 |
| Trim — throttle / elevator / rudder | ±200 µs (**±20 %** of channel width) | 0 |
| Expo — elevator / rudder | 0–50 % | 25 |
| Dual rate — elevator / rudder | 30–100 % | 100 |
| Throttle limit | 20–100 % | 100 |

Expo uses the industry-standard curve `y = x·((1−e) + e·x²)`: it softens the middle without
giving up any authority at the endpoints. 25 % keeps a first flight from feeling twitchy.

Throttle is limited twice — once here, once against the aircraft's own stored ceiling. The
two are independent and the lower one wins.

Servo direction, sub-trim and endpoints are **not** here. Those belong to the airframe and
live in the aircraft's flash; this board just drives the calibration screen.

---

## How it works

* **A dependency-free WebSocket server** — [`include/mini_ws.h`](include/mini_ws.h), SHA-1 and
  base64 included. `WebServer` stamps `Connection: close` on every response, so 20 Hz stick
  updates meant a fresh TCP handshake per frame and visibly jittery surfaces. A flight-ready
  firmware also should not need the internet to compile, which ruled out pulling in a
  library. The handshake accumulates across `loop()` passes and never blocks.

* **Sends are gated behind a zero-timeout `select()`.** `WiFiClient::write()` retries a
  stalled socket ten times with a one-second timeout each — up to ~10 s of blocking. The
  flight loop must never be the thing that waits, and a skipped status frame costs nothing.

* **Non-blocking radio transmit.** `startWrite()` plus STATUS polling instead of
  `radio.write()`, which blocks until ACK or until all retries are exhausted — about 12 ms
  of a 20 ms budget when the link drops, i.e. the controller gets sluggish exactly when
  control matters most. A transmit over 15 ms is aborted and the FIFO flushed; the count
  shows up as `takilan=N`.

* **Broadcast telemetry, and why not unicast.** Unicast was tried and measured out:
  `ack=0 / nack=57` — not one of 57 sends per second acknowledged, then
  `ESP_ERR_ESPNOW_NO_MEM`. The aircraft's STA is not associated with this AP, so its unicast
  frames get no MAC-layer ACK; ESP-NOW retries, the queue fills, telemetry stops completely.
  Broadcast frames expect no ACK and never fill the queue, and the payload carries its own
  magic byte and CRC-8.

* **Calibration commands are retransmitted** every 60 ms until the aircraft echoes the
  matching sequence number, giving up at 1500 ms with a visible error. A config frame takes
  its own 20 ms slot; skipping one control frame is harmless, losing a `SAVE` is not.

* **Self-healing radio.** `radio.begin()` is retried every 3 s and link state comes from a
  live register read, so a wire reseated mid-session recovers without a reset.

* **HTTP fallback stays wired.** If the WebSocket cannot be established the page falls back
  to polling `/c`, and the calibration screen keeps working through `/status`.

---

## Build & flash

```bash
pio run -t upload -t monitor
```

`platformio.ini` pins **COM5** (the CP210x bridge on this board) explicitly. Without it
PlatformIO takes the first port it finds and flashes the aircraft instead. Check yours with
`pio device list`.

The default environment builds only the flight firmware, so a bare `pio run -t upload` can
never leave the diagnostic image on the board.

Roughly 65 % of the app partition, 14 % of RAM.

### Diagnostics

```bash
pio run -e rfdiag -t upload -t monitor      # raw-SPI nRF24 diagnosis
pio run -t upload -t monitor                # back to the transmitter
```

[`diag/rf_diag.cpp`](diag/rf_diag.cpp) bypasses the RF24 library entirely and drives SPI by
hand: shorts, MISO drive, all 12 SCK/MISO/MOSI and CE/CSN permutations, then a speed sweep.
It reports the correct wiring order if the wires got swapped. **It does not bring up WiFi.**

If the registers it reads are bit-shifted copies of each other — `0x08, 0x10, 0x21, 0x42,
0x84` — the MISO line is floating and the module is not answering at all.

### Reading the log

```
[TX] nrf=BAGLI now=BAGLI ws=VAR | web=20/s | kumanda=DISARM ucak=DISARM
     thr=1000 ele=1500 rud=1500 | link=98% | rx=OK 50Hz kayip=%0 vbat=0mV
```

`web=0/s` means the problem is the browser, not the radio — the page is not sending.
`ws=yok` means the WebSocket never came up and the HTTP fallback is carrying control.

---

## Layout

```
src/main.cpp            radio, safety chain, HTTP + WebSocket endpoints, NVS
include/rc_protocol.h    wire format — byte-identical copy in flight_software
include/mini_ws.h        WebSocket server, no external dependency
include/web_ui.h         the phone interface, one PROGMEM string
diag/rf_diag.cpp         raw-SPI nRF24 diagnosis (separate environment)
```

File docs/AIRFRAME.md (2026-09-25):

# RC Plane — Mekanik Tasarım Kararları

3 kanallı (gaz, elevator, rudder) eğitim uçağı. 5 mm fotobloktan elde kesildi.
Aileron yok: yatış, kanadın dihedral kırımı ve rudder ile sağlanıyor.

Aşağıdaki değerler **yapılmış uçağın** değerleri. İlk tasarım planından üç önemli fark var:
polihedral (640/380 bölünmesi) terk edildi ve dihedral tam ortaya alındı, kanat hücum kenarı
montajda 285 yerine 230'a geldi, uçuşa hazır ağırlık 976 g tahmini yerine **1106 g** çıktı.

Gövde ölçüleri

Tüm ölçüler mm. Sıfır noktası firewall.

---

## 1. Kanat

| | |
|---|---|
| Açıklık / veter | 1400 / 200 sabit |
| Alan | 28 dm² |
| Plan | Dikdörtgen, sivrilme yok |
| Dihedral | **10°**, tam ortadan tek kırım — uçta ≈ 123 mm yükselme |
| Profil | KFm-2, basamak hücum kenarından 100 mm (%50 veter) |
| Kalınlık | Ön yarı 10 mm, arka yarı 5 mm |
| Kiriş | Hücum kenarından 50 mm geride |

- Üst katman iki şeride bölünüp **çıta aralarına gömüldü**; üst ve alt çıta çifti birlikte
  I-kiriş gibi çalışıyor.
- Kökte kiriş bindirmesi en az 200 mm, alt ve üstte takviye plakası. Eğilme momenti en çok
  kökte, çift kalınlık oraya denk geliyor.
- **Alt yüz baştan sona şeffaf bantlı:** hem nem bariyeri hem burulma rijitliği.
- Aileron bölgesi (uçtan 250 × 45 mm) işaretlendi ama **kesilmedi**. Firmware ve protokol
  4 kanalı zaten destekliyor; kanat sonradan aileronlu hale getirilebilir.

## 2. Gövde

| | |
|---|---|
| Uzunluk | 1050 |
| Kesit | 75 × 80 |
| Kuyruk | Üst kenar düz; yükseklik alttan daralarak 45 mm'ye iniyor, genişlik sabit 75 |
| Firewall | 3 mm, 3D baskı ([`Firewall.stl`](../cad/print_files/Firewall.stl)), epoksi, 20 mm yuvaya oturuyor |

- Yan duvar eki **x=400**, üst güverte eki **x=600**. İkisi bilerek aynı istasyona
  getirilmedi; aynı kesitte buluşurlarsa gövde orada zayıflar.
- Kanat bölgesine (x=285–485) iç yüzden **çift kat doubler**.
- Ara bölmeler: **x=150, 285, 485, 750**.
- **İniş takımı yok:** elden fırlatma, karın inişi. Burun altına kurban şeridi ve bant.

## 3. Yerleşim ve denge

| | |
|---|---|
| Kanat hücum kenarı | x=230 *(tasarımda 285 idi, montajda 230'a geldi)* |
| **Ağırlık merkezi** | **x=278** (ölçülen) — hücum kenarından 48 mm, veterin %24'ü; hedef x=280 (%25) |

- **Batarya cırt bantla ayarlanabilir.** CG'nin tek düzeltme aracı bu; kurşun eklenmiyor.
- **Kanat gövdeye yapışık değil:** iki ahşap pim + kauçuk lastik. Sert bir inişte kanat
  yerinden çıkıyor — tasarlanmış kırılma noktası.

## 4. Açılar

| | |
|---|---|
| Kanat hücum açısı | +1,4° (5 mm takoz) |
| Yatay dengeleyici | 0° — dekalaj 1,4° |
| Motor | 2° aşağı, 2° sağ |

Firewall dik kesildi; motor açıları montaj pulu ile veriliyor.

## 5. Kuyruk

| | |
|---|---|
| Yatay | 400 × 150 (kanadın %21'i), **Vh = 0,70** |
| Elevator | Veterin %35'i = 52 mm |
| Dikey | 180 yükseklik, kök 140 / uç 100, **Vv = 0,036** |
| Rudder | 50 mm sabit genişlik, firar kenarı dik |
| Kuyruk momenti | ~630 mm = 3,1 × veter |

- **Menteşe:** iki yüzden 45° tıraş, tek taraftan bant.
- **Sapmalar:** elevator ±14 mm, rudder ±20 mm. Mekanik nötr ayarlı; ince ayar
  arayüzdeki servo kalibrasyonundan yapılıyor (yön, nötr, uç noktalar uçağın NVS'inde).

## 6. Güç sistemi

| | |
|---|---|
| Motor / pervane | A2212 1000 KV / 10×4.5 |
| ESC | 30 A |
| Batarya | 3S 2200 mAh 30C |
| 5 V | **Ayrı UBEC, 5 V / 3 A** — ESC'nin lineer BEC'i devre dışı |
| Akım hedefi | Tam gazda 25 A altı |
| Tam gaz (eCalc) | ≈ 15,1 A, 161 W, 8680 d/d, ≈ 912 g statik itki — ölçülmedi |

ESC'nin lineer BEC'i devre dışı bırakıldı; kart ve iki servo ayrı UBEC'ten besleniyor.
Sebebi yaşandı: servolara sinyal gidince kart çöküyordu — önce ESP32-C3'te, DevKitC'ye
geçince yine. Sorun yazılım değil beslemeydi; 9 g servo ani harekette ~700 mA çekiyor ve
12 V'u 5 V'a düşüren lineer BEC hattı tutamıyordu. Ayrı UBEC'ten sonra çökme bitti.
Bağlantı şeması: [`diagrams/aircraft_wiring.svg`](diagrams/aircraft_wiring.svg).

## 7. Malzeme ve yapım

- **5 mm kraft fotoblok**, 50 × 70 cm levha. Hiçbir parça 700 mm'yi geçmiyor; gövdenin uzun
  parçaları ekleme yapılarak elde edildi.
- **Sıcak silikon** ana yapıştırıcı; epoksi yalnızca firewall'da.
- **Ahşap çıta kiriş** (karbon yerine).
- Tutkal **köpük yüzeye** sürülüyor, kağıda değil.

Yapım sırası: test parçası (45° eğik kesim, çizik derinlikleri, bant menteşe) → 1:1 şablonlar
→ kanat panelleri ve çıta → ortadan dihedral kırımı → kök takviyesi → gövde yan duvarları,
ekler, doubler'lar, firewall → ara bölmeler → **UBEC hattını masada dene** → elektronik ve
üst güverte → kuyruk yüzeyleri → pushrod ve mekanik nötr → son CG ölçümü.

## 8. Kütle

| | |
|---|---|
| Uçuşa hazır | **1106 g** |
| Kanat yükü | 39,5 g/dm² |
| İtki/ağırlık | ≈ 0,83 *(eCalc, ölçülmedi)* |

İtki/ağırlık ≈ 0,83 olduğu için dik tırmanış yok: elden fırlatmada burnu fazla kaldırmamak,
hızı toplamasını beklemek gerekiyor. 0,83 **statik** bir oran; uçuş hızındaki itki bunun çok
altında — bkz. §9.

**CG kontrolü:** uçak bataryalı ve tam donanımlıyken, kanadın altından iki parmakla hücum
kenarından 50 mm geriden tut. Yatay durmalı ya da burnu hafif aşağı bakmalı. Kuyruk
düşüyorsa bataryayı öne kaydır.

## 9. Uçuş testleri ve performans analizi

### Ne oldu

Sürülmüş tarlada elden atış; ilk oturum 21 Eylül 2026, sonra bir akşam oturumu. Telsiz her
seferinde çalıştı, uçak havada kalmadı. Her atış **tam kolda**, ayarlar varsayılanda (gaz
sınırı %100, uçak tavanı yok) ve ESC kalibre edilmişken yapıldı. Kodda bu, arada başka
kısıt olmadan 2000 µs darbe demek (kumandada `gazUs()`, uçakta `escYaz()`). Süreler
videolardan kare sayılarak çıkarıldı (30/60 fps).

| Atış | Videoda görünen |
|---|---|
| En iyi (21 Eylül) | Elden çıkıyor, biraz tırmanıyor, sonra yavaş yavaş irtifa kaybediyor, kurtarılamıyor — ~10 s. Pilotun yorumu: rüzgâr yardım etti |
| Yumuşak, burun yukarı | Yavaş ve burnu kalkık bırakılıyor, bir kanat düşüyor, bırakıştan **1,2 s** sonra yerde |
| Yukarı fırlatma | Pilot tek elle dik yukarı atıyor, telefon öbür elde; birkaç metre çıkıyor, geri çöküyor, **~4,5 s** sonra yerde |

Kamera her klipte hareketli olduğu için hız ve alçalma oranı videodan güvenilir ölçülemiyor.

### Model

Uçuş performansı

[`diagrams/flight_model.py`](diagrams/flight_model.py): noktasal kütle, boyuna düzlem. Ölçüm
değil, model — varsayımlar tek yerde, ölçüldükçe değiştirilecek. Testler tam gazda yapıldığı
için eğriler gaz yüzdesine göre değil, **tam gazdaki statik itkiye** göre çiziliyor: ölçülmemiş
en büyük girdi o.

| Varsayım | Değer | Nasıl doğrulanır |
|---|---|---|
| Statik itki, tam gaz | ≈ 912 g (eCalc) — **ölçülmedi** | El kantarı / mutfak terazisi |
| CLmax | 0,9 (KFm-2, Re ≈ 130 000) | XFLR5 polarları |
| CD0 | 0,05 (bant 0,04–0,07) | XFLR5 + sabit kameradan süzülüş |
| Oswald e | 0,75 | XFLR5 |
| Hıza göre itki düşüşü | Staples yaklaşık denklemi | Ses spektrumundan devir (phyphox) |
| Hava yoğunluğu | 1,20 kg/m³ | — |

| Sonuç | Değer |
|---|---|
| Stall hızı | ≈ 8,5 m/s |
| En az sürükleme hızı | ≈ 8,4 m/s — stall ile aynı |
| Adım hızı (10×4.5) | ≈ 16 m/s; 10 m/s'de itki statiğin %38'i |
| Tam gaz, ≈ 912 g statik (eCalc) | Yatay uçuş 8,5–13,1 m/s, en iyi tırmanış ≈ 2,4 m/s |
| Tam gaz, 650 g statik | Yatay uçuş 8,5–10,8 m/s, tırmanış ≈ 1,0 m/s |
| İrtifa tutulamayan statik itki | ≈ 440–500 g altı (itki/ağırlık 0,4–0,45) |
| ≈ 912 g ile irtifa tutulamayan CD0 | ≈ 0,3 — bağlı akışta olanaksız, ancak stall'da |
| Motorsuz, 2 m'den | 1,6 s'de yerde |

Atış simülasyonu: 2 m yükseklik, 8,5 m/s, elevator sabit (9,3 m/s'ye trimli), pilot
müdahalesi yok. ≈ 912 ve 650 g tırmanıyor, 450 g yere iniyor (4,3 s).

### eCalc karşılaştırması

Aynı güç sistemi [eCalc propCalc](https://www.ecalc.ch/)'ta çalıştırıldı (A2212 1000 KV,
10×4.5, 3S 2200 mAh 30C, 1105 g). Modelin statik itkisi buradan geliyor.

| | eCalc |
|---|---|
| Tam gaz | 15,14 A, 10,52 V, 159 W elektrik / 131 W mekanik, 8680 d/d, verim %82,5 |
| En iyi verim noktası | 7,26 A, 78,5 W, 9766 d/d, verim %86,6 |
| Batarya | 6,88 C yük, 10,64 V; tam gazda 7,4 dk, karışık uçuşta 10,6 dk |
| Motor sıcaklığı | ~42 °C (15 s tam gazda) |
| Statik itki | ≈ 912 g, özgül itki 5,73 g/W, itki/ağırlık 0,83 |
| Adım hızı / uç hızı | 60 km/h (16,7 m/s) / 416 km/h |
| Stall / yatay hız | 30 km/h (8,3 m/s) / 68 km/h (18,9 m/s) |
| Tırmanma | 4,5 m/s (~25–30°) |

eCalc stall ve adım hızında modelle uyuşuyor, gerisinde daha iyimser (tırmanış 4,5'e
karşı 2,4 m/s). Sonuç hangisinin doğru olduğuna bağlı değil: kağıt üzerinde bu güç
sistemi tırmanıyor.

### Yorum

- **Kağıt ile saha çelişiyor — bulgu bu.** eCalc'ın ≈ 912 g'ı ile iki hesap da tam gazda
  tırmanış veriyor; uçak tırmanmadı. Model yavaş düşüşü yalnızca iki durumda üretiyor: motor ~500 g'ın altında
  itki veriyorsa, ya da kanat stall'un ötesinde uçuyorsa (orada sürükleme bu modelin çok
  üstünde).
- **Güç mü, hız mı?** Düşüş düşük hızda oluyor: uçak stall hızından hiç kurtulamıyor. Onu
  orada tutan ya itkinin hızlanmaya yetmemesi, ya da kanadın fazla yüksek açıda tutulması
  (burun yukarı bırakış, çekili elevator). Tek ölçüm ikisini ayırıyor: statik itki ~800 g ve
  üstüyse güç zinciri temiz, sorun atış ve trim; ~500 g ve altıysa sorun güç zinciri.
- **Hız payı yok.** En az sürükleme hızı stall'un üstüne oturuyor. Uçağı yavaşlatan her şey
  (yumuşak atış, burun yukarı bırakış, düşüşü durdurmak için elevator çekmek) sürüklemeyi
  artırıp düşüşü hızlandırıyor.
- **Rüzgâr — en iyi uçuş şans olabilir.** Karşı rüzgâra atılan uçak elden atış hızı *artı*
  rüzgâr hızıyla ayrılır; bir hamle (gust) de bir anlığına hız ekler. Stall ile en az
  sürükleme hızı üst üste olduğu için rüzgârın kısa bir kesilmesi uçağı yeniden düşüşe sokar.
  Rüzgârın yapamayacağı: sabit rüzgâr, uçak havadayken hava hızını değiştirmez; rüzgâr
  yönüne dönmek yer hızını değiştirir, hava hızını değil. Düşen uçağı yalnızca yükselen hava
  taşır. Rüzgâr ölçülmedi, bu yüzden hipotez olarak kalıyor.
- **Süzülerek kurtulamaz.** 10 saniye havada kalması motorun çektiğini gösteriyor; eksik olan
  güç **payı**.

### Nerede yanıldım

- Tasarımı statik sayılarla doğruladım (itki/ağırlık, kuyruk hacimleri, CG); uçuş hızındaki
  itki ile sürüklemeyi hiç karşılaştırmadım.
- İtkiyi hiç ölçmedim. 0,83 oranı eCalc tahmini; "yerde ilerlemeye başladı" yalnızca itkinin
  yer sürtünmesini yendiğini gösterir — ağırlığın küçük bir kesri.
- Ağırlık %13 arttı (976 → 1106 g), kanat yükü 35 → 39,5 g/dm²; payı yeniden hesaplamadım.
- Atışlar yumuşak ya da burun yukarıydı, biri tek elle.
- Belgeler ilk uçuş için %70–80 gaz sınırı öneriyor — bu pay için yanlış (testler %100'de
  yapıldı).
- Veri olmadan uçtum: uçuş kaydı, sabit kamera, ölçülmüş itki, rüzgâr ölçümü yok.

### Dışarıdan gelen öneriler

| Öneri | Değerlendirme |
|---|---|
| 10×4.5 yerine 9×6 pervane | **İşe yarar** — adım hızı 16 → 22 m/s, en iyi tırmanış 2,4 → 2,7 m/s (8700 d/d varsayımıyla — eCalc'ta denenecek). Akım kontrolü |
| 2200 yerine 1300–1500 mAh batarya | Küçük etki — ~−80 g, stall −%4; CG yeniden ayarlanmalı |
| Kağıdı soyulmuş fotoblok / XPS ile 750–800 g'da yeniden yapım | **En büyük kaldıraç** — stall 7,0–7,2 m/s, kanat yükü 27–29 g/dm² |
| KFm-2 yerine Clark Y / NACA 4412 | Makul, daha az sürükleme; yeni kanat demek, ucuz çözümlerden sonra |
| Spiral dalışa karşı dikey kuyruk +%15–20 | **Desteklenmiyor.** Vv 0,036 olağan aralıkta (0,02–0,05). Büyük dikey kuyruk spiral ıraksamayı *artırır*; güçlü dihedral + küçük kuyruk daha çok Dutch roll'a eğilimlidir. XFLR5 kararlılık analizi gerekir |
| Dokunmatik rudder'a expo / ölü bölge | Expo zaten var (varsayılan %25); ölü bölge yok, eklemesi ucuz |

Parça almadan yapılacak ölçümler ve yazılım işleri: kök `README.md` → *Next Steps*.

---

## İlk plandan neler değişti

| Konu | Plan | Yapılan |
|---|---|---|
| Kanat kırımı | Polihedral, 640 + 380 panel, ±320'de kırım | 10° dihedral, ortadan tek kırım |
| Kanat hücum kenarı | x=285 | x=230 |
| 5 V | ESC'nin BEC'i | Ayrı UBEC 5 V / 3 A, ESC BEC devre dışı |
| Ağırlık | 976 g tahmini | 1106 g ölçülen |
| Kanat yükü | 35 g/dm² | 39,5 g/dm² |

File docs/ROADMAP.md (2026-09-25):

# RC Plane — Geliştirme Yol Haritası

Sistem uçuyor: telsiz, arayüz, failsafe ve kumanda zinciri çalışıyor. Bu belge bundan
sonra ne yapılacağını, **neden** yapılacağını ve **ne zaman bitmiş sayılacağını** yazıyor.

Sıra, "en çok şeyi en az emekle değiştiren" işe göre dizildi. Emek tahminleri kabaca ve
tek kişilik çalışmaya göre.

| Sıra | İş | Emek | Neyi değiştirir |
|---|---|---|---|
| 1 | Depo ve belge temizliği | 1 gün | Projenin dışarıdan görünen hali |
| 2 | Link güvenliği (kimlik doğrulama) | 1–2 hafta | Sistemin en büyük açığı |
| 3 | Menzil ve link ölçümü | 2 gün + saha | "Verisi var mı" sorusunun cevabı |
| 4 | Telemetri ve uçuş kaydı | 1 hafta | Uçuşları analiz edebilmek |
| 5 | IMU ve stabilizasyon | 3–6 hafta | Projeyi İHA uçuş kontrolcüsüne çevirir |
| 6 | Donanımın olgunlaşması | 1–2 hafta | Güvenilirlik |
| 7 | Test altyapısı ve CI | 3–5 gün | Mühendislik süreci |
| 8 | 4 kanal (aileronlu kanat) | 1 hafta | Firmware zaten hazır |
| 9 | Frekans atlama (FHSS) | 2 hafta | Parazite ve karıştırmaya direnç |
| 10 | GPS ve eve dönüş | 4+ hafta | Otonomiye giriş |

---

## 1. Depo ve belge temizliği

Kısa işler, hepsi bugün bitebilir:

- [ ] `LICENSE` ekle (MIT önerisi). Lisanssız depo teknik olarak "tüm hakları saklı".
- [ ] Ana projedeki belge tutarsızlıkları: `RcPacket` sürüm 3'te **12 byte** ama
      `controller_software/README.md` ve `RF_PROTOKOL.md` hâlâ 10 byte diyor; protokol
      belgesinin başlığı "Sürüm 2".
- [ ] Ayarlar'daki **3 kanal / 4 kanal** seçimi hiçbir README'de anlatılmıyor.
- [x] Tartılmış ağırlık ve ölçülen CG → `AIRFRAME.md` tablosundaki tahminlerin yerine.

## 2. Link güvenliği — kimlik doğrulama ve tekrar koruması

**Sorun.** CRC-8 yalnızca bozulmayı yakalıyor, saldırıyı değil. Protokolü bilen biri aynı
kanaldan `"RCP01"` adresine geçerli paket üretirse uçağı kontrol edebilir; kaydedilmiş bir
paketi yeniden göndermek (replay) de mümkün. Hobi uçağı için kabul edilebilir, savunma
tarafında konuşulan ilk konu bu.

**Yapılacak.**
- Her iki karta NVS'te duran **paylaşılan anahtar** (ilk eşleşmede üretilip USB'den girilir).
- Her pakete kısaltılmış **AES-CMAC etiketi** (4 byte yeterli) — ESP32'de donanım AES var,
  `mbedtls` ile 50 Hz bütçesinde rahat kalır.
- `seq` alanını **monoton sayaç** olarak kullan; pencere dışındaki ve tekrar eden sayaçları
  reddet. Sayaç zaten var, yalnızca kuralı sıkılaştırmak gerekiyor.
- Paket 12 → 16 byte olur; `RC_PROTO_VER` artar, iki kart birden yüklenir.

**Bitti sayma ölçütü.**
- Üçüncü bir ESP32 ile üretilen sahte paket ve kaydedilmiş paketin tekrarı **reddediliyor**,
  seri logda red sayacı artıyor.
- Çerçeve süresi hâlâ 20 ms'nin altında; `[TX]` logunda gecikme artışı yok.
- Failsafe ve arm kilidi davranışı değişmiyor (aynı test senaryoları tekrar geçiyor).

**Neden değerli.** Mülakatta "linki nasıl güvene alırsın" sorusuna kodla cevap verebilmek.

## 3. Menzil ve link karakterizasyonu

**Yapılacak.** Açık alanda 50 / 100 / 200 / 400 m'de, her PA seviyesinde ve iki anten
yönünde ölçüm: `rxHz`, paket kaybı %, `kurt` / `kurtarma` sayaçları, failsafe'e düşme
sayısı. nRF24'te RSSI yok; RPD biti ve kayıp oranı kullanılır, ESP-NOW tarafında RSSI
okunabiliyor.

**Çıktı.** `docs/RANGE_TEST.md`: yöntem, ham tablo ve mesafeye karşı kayıp grafiği.
Grafiği README'ye koy — ölçülmüş veri, iddiadan daha ikna edici.

## 4. Telemetri ve uçuş kaydı

- **Batarya.** ADC1 pinine (ör. GPIO35) gerilim bölücü, `bataryaOku()` doldurulur, iki
  noktadan kalibrasyon. Arayüzdeki `BAT --` alanı kendiliğinden çalışmaya başlar.
- **Kayıt.** Yer istasyonu her çerçeveyi CSV'ye yazar (zaman, kanallar, `rxHz`, kayıp,
  voltaj, durum bitleri), arayüzden indirilir.
- **Bitti ölçütü.** Uçuş sonrası kaydı indirip grafiğe dökebiliyorsun; düşük voltajda
  arayüz uyarı veriyor.

Bu, 5. maddenin de önkoşulu: stabilizasyonun işe yarayıp yaramadığı ancak kayıtla anlaşılır.

## 5. IMU ve stabilizasyon — en büyük sıçrama

**Yapılacak.**
- IMU (MPU6050 başlangıç için yeterli, ICM-42688 daha iyi), titreşim yalıtımlı montaj.
- Tamamlayıcı ya da Mahony filtresiyle yatış/yunuslama tahmini; jiroskop sapması
  (drift) kalibrasyonu.
- 3 kanalda döngüler: yatış → rudder, yunuslama → elevator. PID, çıkış sınırları ve
  integral birikme (anti-windup) koruması.
- Modlar: **manuel** (bugünkü davranış), **stabilize**, ve en değerlisi
  **failsafe kurtarma**: link koptuğunda kanatları seviyeye getirip gazı kısarak süzülüş.
  Bugün failsafe uçağı yalnızca nötre alıyor; kurtarma gerçek bir emniyet özelliği olur.
- IMU arızası ya da tahmin sapması → otomatik manuele düşme.

**Test sırası.** Tezgahta (pervanesiz) kartı elde çevirip çıkışların doğru yöne gittiğini
gör → yüksek irtifada, geniş alanda, moda geçip hemen manuele dönerek dene → tam uçuş.

**Neden değerli.** İHA ekiplerinin çekirdek işi bu. Stabilizasyon eklendiğinde proje
"uzaktan kumanda" olmaktan çıkıp "uçuş kontrol yazılımı" oluyor.

## 6. Donanımın olgunlaşması

- Breadboard → delikli kart, sonra **KiCad** ile PCB (`hardware/kicad/`).
- ~~Servolara ayrı UBEC~~ — yapıldı: servolar hareket edince kart çöküyordu, ayrı
  5 V / 3 A UBEC ile bitti.
- Konnektörler (servo ve besleme ayrı), titreşim yalıtımı, anten yerleşimi ve gövde
  içinde kablo düzeni.
- Uçuş öncesi kontrol listesine "kablo çekiştirme testi" ekle.

## 7. Test altyapısı ve CI

- **Host üstünde birim testleri** (PlatformIO `native` ortamı): CRC, paket paketleme ve
  çözme, kalibrasyon eşlemesi, gaz eğrisi, failsafe durum makinesi.
- **GitHub Actions:** iki firmware derlemesi + `tools/run_all.mjs`. Depoya yeşil rozet.
- Küçük bir **gereksinim → test izlenebilirlik tablosu** (hangi güvenlik kuralını hangi
  test koruyor). Savunma sanayinde süreç bilinci, kodun kendisi kadar dikkat çeker.

## 8. Aileronlu kanat (4 kanal)

Firmware ve protokol hazır: aileron kanalı sürüm 3'te var, uçak GPIO 32/33'e aynalı çıkış
veriyor, arayüzde "4 kanal" seçeneği çalışıyor. Geriye yalnızca aileronlu bir kanat ve
iki servo kalıyor. Aynı uçakta iki kanadı karşılaştırmak (polihedral + rudder ile aileron)
güzel bir ölçüm yazısı olur.

## 9. Frekans atlama (FHSS)

Sabit kanal, hem WiFi parazitine hem kasıtlı karıştırmaya açık. Ortak bir atlama dizisi
(anahtardan türetilir), paket başına kanal değişimi ve yeniden senkron kuralı. 2. madde
bittikten sonra mantıklı: anahtar zaten paylaşılmış olur.

## 10. GPS ve otonomi

GPS modülü, konum telemetrisi, eve dönüş ve bağlantı kopmasında bekleme (loiter).
Bu noktada **ArduPilot / PX4 ve MAVLink**'i tanımak gerekir: kendi kodunu yazmaya devam
etsen bile sektörün ortak dili bu.

---

## Kapsam dışı bıraktıklarım

- **Gerçek zamanlı işletim sistemi (RTOS) görevlerine bölmek:** döngü bugün 20 ms
  bütçesini tutuyor, karmaşıklık kazancı karşılamıyor.
- **Kendi telsiz protokolünü LoRa'ya taşımak:** menzil artar ama gecikme kontrol için
  uygun değil.

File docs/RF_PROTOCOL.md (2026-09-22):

# RC Plane — Telsiz Protokolü ve Sistem Raporu (Sürüm 2)

Kumanda (ESP32 WROOM-32 + nRF24L01) ↔ Uçak (ESP32 DevKitC + ESC/servolar) arası veri akışının
tam tanımı. İki firmware de bu belgeye göre yazıldı.

> **Sürüm 2 uyarısı:** Uçak **3 kanallı** oldu (gaz + elevator + rudder), aileron kaldırıldı.
> Paket formatı ve `magic` değerleri değişti. **Sürüm 1 firmware ile uyumsuzdur** —
> iki kartı da birlikte yükle.

---

## 1. Sistem özeti

| | Kumanda (`controller_software`) | Uçak (`flight_software`) |
|---|---|---|
| Kart | ESP32 DevKit (WROOM-32) | ESP32 DevKitC 38 pin (WROOM-32D) |
| Rol | WiFi AP + web arayüzü + verici | Alıcı + servo/ESC sürücü |
| Port | COM5 (CP210x köprü) | COM6 (USB köprü — ilk takışta `pio device list` ile doğrula) |
| Kalıcı ayar | Pilot ayarları (trim/expo/oran/mod) | Servo kalibrasyonu (yön/nötr/uç) |

**Ayarların hangi tarafta durduğu bilinçli bir karar:**
uç noktalar ve nötr **uçağın** özelliği (linkaj mekaniği), trim ve expo **pilotun**
özelliği. Bu yüzden kalibrasyon uçağın NVS'inde, trim/expo kumandanın NVS'inde.
Telefonu değiştirmek hiçbirini kaybettirmez.

---

## 2. Donanım / pin bağlantısı

### Kumanda tarafı — nRF24L01

| nRF24L01 | ESP32 pini | Kablo rengi |
|---|---|---|
| VCC  | **3V3** (5V değil!) | kırmızı |
| GND  | GND | siyah |
| CE | GPIO4  | mavi |
| CSN  | GPIO5  | magenta |
| SCK  | GPIO18 | turuncu |
| MOSI | GPIO23 | camgöbeği |
| MISO | GPIO19 | yeşil |
| IRQ  | bağlı değil | — |

**SPI hızı:** `RF_SPI_HZ = 4000000`. Kütüphane varsayılanı 10 MHz; dupont kablo +
breadboard ile o hız çoğu zaman güvenilir değil.

**Kondansatör zorunlu:** nRF24 yayın anında akım tepesi çeker; kartın 3V3 regülatörü bunu
karşılamazsa modül brown-out olur ve `radio.begin()` bazen geçer bazen geçmez.
**VCC–GND arasına, modül bacağına en yakın noktaya 10–100 µF** koy.

**Konnektör yönü:** nRF24 header'ı 2×4'tür, **1. bacak GND, 2. bacak VCC**. Bir sıra
kaydırmak çok kolay ve VCC/GND ters gelirse modül yanar. Taktıktan sonra modüle dokun —
ılıksa hemen çek.

### Uçak tarafı (ESP32 DevKitC 38 pin) — 3 kanal

Tam şema: `flight_software/docs/kablolama.html`.

| İşlev | GPIO | Not |
|---|---|---|
| **ESC (gaz)** | **GPIO25** | Sinyal–GND arası 10k; boot sırasında ESC'ye çöp darbe gitmiyor |
| **Elevator servo** | **GPIO26** | |
| **Rudder servo** | **GPIO27** | |
| nRF24 SCK | GPIO18 | kumandayla aynı |
| nRF24 MISO | GPIO19 | kumandayla aynı |
| nRF24 MOSI | GPIO23 | kumandayla aynı |
| nRF24 CSN | GPIO5 | kumandayla aynı |
| nRF24 CE | GPIO4 | kumandayla aynı |

Kaçınılan pinler: **GPIO 0, 2, 12, 15** (strapping), **14** (boot'ta PWM), **6–11**
(flash — kartta `D0–D3`, `CMD`, `CLK` yazar; `D2` GPIO2 değil), **1, 3** (UART0).

**Beslemeler:** nRF24 mutlaka 3.3 V (38 pinli kartta 3V3 sol üst pin). Kart ve servolar
**ayrı bir UBEC'ten** (5 V / 3 A) besleniyor, ESC'nin lineer BEC'i devre dışı; 5 V hattında
5V–GND arası kondansatör var. GND'ler ortak olmalı.

Uçak boot logunda reset sebebini basıyor. `BROWNOUT` görüyorsan sorun besleme, yazılım
değil — kod bunu düzeltemez.

### Telsiz çalışmıyorsa: otomatik teşhis

```
pio run -e rfdiag -t upload -t monitor
```

`diag/rf_diag.cpp` — RF24 kütüphanesini hiç kullanmadan ham SPI ile 4 test yapar:
kısa devre, MISO sürücü, pin sıralaması (12 kombinasyon), hız taraması.
**Bu firmware WiFi açmaz**; kumandaya dönmek için `pio run -t upload -t monitor`.

Beklenen register değerleri (reset sonrası): `STATUS=0x0E`, `CONFIG=0x08`, `SETUP_AW=0x03`,
`EN_AA=0x3F`, `RF_CH=0x02`, `RF_SETUP=0x0E`. Okunan değerler birbirinin **bit
kaydırılmışı** ise (örn. `0x08, 0x10, 0x21, 0x42, 0x84`) MISO hattı boştadır.

---

## 3. İki taşıma katmanı: nRF24 + ESP-NOW

Aynı paket iki bağımsız yoldan gidebilir. Her ikisi de aynı doğrulamadan (magic + CRC +
protokol sürümü), aynı arm kilidinden ve aynı failsafe yolundan geçer — kurallar tek
yerde, uçak tarafında `paketIsle()` içinde.

| | nRF24 | ESP-NOW |
|---|---|---|
| Donanım | Ayrı modül + 7 kablo + kondansatör | **Yok** — çipin kendi WiFi radyosu |
| Frekans | 2.508 GHz (kanal 108) | 2.412 GHz (WiFi kanal 1) |
| Adresleme | `"RCP01"` pipe | Yayın — **MAC eşleştirmesi gerekmez** |
| Geri yol | ACK payload | Ayrı yayın paketi |

Açma/kapama, iki projede de dosyanın başındaki sabitlerle:

```cpp
static const bool USE_NRF24  = true;
static const bool USE_ESPNOW = true;
```

**Tek şart:** kumandanın `AP_CHANNEL` değeri ile uçağın `ESPNOW_CHANNEL` değeri aynı
olmalı (ikisi de 1).

İkisi birden açıkken yedekli link olur: uçak aynı paketi iki yoldan alabilir, `seq` farkı
≤ 0 olduğu için ikincisi tekrar sayılıp atılır (çıkışlar iki kez yazılmaz). Bir yol tamamen
ölse bile uçuş devam eder.

> **Telemetri neden yayın?** Unicast denendi ve ölçüm reddetti: `ack=0 / nack=57` — saniyede
> 57 gönderimin hiçbiri ACK almadı, ardından `ESP_ERR_ESPNOW_NO_MEM` geldi. Uçağın STA'sı
> kumandanın AP'sine ilişkilendirilmiş değil; ilişkilendirilmemiş bir STA'dan AP'ye giden
> unicast çerçeve MAC seviyesinde ACK almaz, ESP-NOW tekrar tekrar dener, kuyruk dolar ve
> telemetri tümden durur. Yayın çerçevesi ACK beklemez, kuyruğu doldurmaz.

### nRF24 ayarları (iki tarafta birebir aynı olmalı)

| Ayar | Değer |
|---|---|
| Kanal | `108` (2.508 GHz) |
| Adres | `"RCP01"` (5 byte) |
| Veri hızı | `RF24_250KBPS` (`RC_RF_DATARATE = 2`) |
| CRC | `RF24_CRC_16` (donanımsal) |
| Retries | `setRetries(5, 3)` — ARD 1500 µs, 3 tekrar |
| PA seviyesi | `RF24_PA_HIGH` — aşağıdaki nota bak |
| Dinamik payload | açık |
| ACK payload | açık (telemetri + kalibrasyon raporu) |
| Gönderim hızı | **50 Hz** (20 ms) |

**MAX_RT ve TX FIFO kilidi — "link ölüyor, bir daha geri gelmiyor":**
Oturumun en pahalıya patlayan hatası buydu. nRF24, bütün tekrarlar
tükendiğinde (`MAX_RT`) başarısız paketi TX FIFO'dan **atmaz**;
temizlemek yazılıma düşer. `radioPoll()` bayrakları temizliyor ama
`flush_tx()` çağırmıyordu. Zincir:

1. Üç ardışık başarısız gönderim → TX FIFO dolar
2. `startWrite()` `false` döner → `txPending` false kalır
3. `radioPoll()` `if (!txPending) return;` ile **bir daha hiç koşmaz**
4. FIFO sonsuza kadar dolu → telsiz **kalıcı olarak kilitli**
5. Cip SPI'dan cevap verdiği için durum satırı hâlâ `nrf=BAGLI` der

Teşhis imzası: `cevapsiz=` sayacı **tam 3'te** (FIFO derinliği) donup kalır,
`takilan=0`, `ack=0`, `tur=49/s` — yani loop sağlıklıyken gönderim hiç
başlamıyor. Menzil kenarında ya da uçak bir an resetlendiğinde üç ardışık
başarısızlık çok kolay oluşuyor.

Çözüm: `MAX_RT`'de `flush_tx()`, ve `startWrite()` false dönerse de
`flush_tx()`. Bayat bir kontrol çerçevesini saklamanın değeri yok — 20 ms
sonra tazesi geliyor.

**PA seviyesi — düşürüldü, sonra geri yükseltildi:**
Bir ara `PA_LOW`'a inilmişti: `PA_HIGH` ile link kumanda boot ettikten ~2 sn
sonra ölüyor ve **bir daha geri gelmiyordu**. Yayın anındaki akım tepesi gibi
görünüyordu.

O **kalıcılığın** asıl sebebi PA değildi — yukarıdaki FIFO kilidiydi. Kilit
kırıldıktan ve sağır modül kurtarması eklendikten sonra PA geri `HIGH`
yapıldı: brown-out olsa bile telsiz kilitlenmek yerine kendine geliyor.

Gerekçe: `PA_LOW`'da menzil kapalı alanda birkaç duvarı geçemiyordu.
`LOW → HIGH` ~+6 dB, kabaca menzilin iki katı.

Brown-out geri gelirse gizlenmiyor: uçakta `kurt=N`, kumandada `kurtarma=N`
sayacları artar. **Artıyorsa** besleme yetersiz — modül bacağına en yakın
noktada 10–100 µF **+ 100 nF seramik** (elektrolitik tek başına RF transient
hızında yavaştır); servo beslemesi zaten ayrı UBEC'te, GND'ler ortak olmalı.

**Menzil beklentisi.** 250 kbps'te alıcı hassasiyeti ~−94 dBm (2 Mbps'te
~−85 dBm), yani seçilen hız tek başına ~9 dB / ~2.8 kat menzil kazandırıyor.
Gerçekçi rakamlar, görüş hattında:

| Kurulum | Menzil |
|---|---|
| PCB iz antenli küçük modül, `PA_HIGH` | ~50–70 m |
| Aynısı `PA_MAX` | ~80–100 m |
| PA+LNA'lı modül + harici anten | 200–500 m |

Kapalı alanda her iç duvar ~3–10 dB yiyor; iki-üç duvar 20 dB'yi geçiyor ve
20 dB menzilin **onda birine** düşmesi demek. Bu yüzden menzil ölçümü
**açık alanda, görüş hattında** yapılmalı. RC uçak için rahat 300 m+
isteniyorsa iz antenli modül yetmez.

**Sağır modül kurtarması:** `radioOk` true kalıp radyo susunca eski kodda
hiçbir kurtarma yolu devreye girmiyordu — mevcut yeniden deneme yalnızca
`!radioOk` iken çalışıyor, `isChipConnected()` ise sağır modülde de geçiyor.
İki taraf da artık şu koşulda cipi baştan kuruyor (`NRF_SAGIR_MS = 2000`):

- **Uçak:** diğer taşıma yolundan paket AKIYOR (yani kumanda kesin yayında)
  ama nRF24 2 sn boyunca hiçbir şey duymadı.
- **Kumanda:** 50 Hz yayın yapılıyor ama 2 sn boyunca hiç ACK gelmedi.

Sayaclar: uçakta `kurt=N`, kumandada `kurtarma=N`.

**İki kademeli watchdog'lar — neden disarm etmiyorlar:**
Hem arayüz hem telsiz watchdog'u eskiden doğrudan `disarm()` çağırıyordu ve
bu, uçuşta **kurtarılamaz** bir duruma sokuyordu: gaz kolu yukarıdayken disarm
olunca ARM kapısı "gaz çıkışı minimumda olmalı" dediği için bir daha arm
edilemiyor, motor kesik kalıyordu. Ölçümde birebir görüldü — aynı red
saniyede 46 kez, pilot gazı indirene kadar. Önlem değil, kaza sebebi.

Her ikisi de artık iki kademeli:

| | 1. kademe | 2. kademe |
|---|---|---|
| Arayüz (`WEB_TIMEOUT_MS`/`WEB_OLU_MS`) | 2 sn: gaz sıfır, yüzeyler nötr, **ARM korunur** | 5 sn: disarm |
| Telsiz (`RF_TEMAS_OLU_MS`) | temas kaybolur kaybolmaz: gaz sıfır, **ARM korunur** | 4 sn: disarm |

Temas = taze telemetri **ya da** donanım ACK'i. Arayüz eşiği 1 sn ile
başladı ve çok sıkı olduğu ölçüldü (telsiz kusursuzken tarayıcı kaynaklı
kısa takılmalar gazı kesiyordu); 2 sn bunları yutuyor.

Bir ara "gaz yeniden kapılama" da vardı — kesintiden sonra arayüzden bir kez
sıfıra yakın gaz gelene kadar gaz uygulanmıyordu. **Kaldırıldı:** koruduğu bir
şey yoktu (`ctrl.thrIn` yalnızca gelen komuttan set edilir ve kesintide
sıfırlanır, dönüşte gelen değer pilotun o anki kol konumudur) ama zararı
vardı: pilot gazı yukarıda tuttuğu sürece kapı açılmıyor, motor kapalı
kalıyordu.

**ARM kapısı bilerek daha sıkı kaldı:** havalanmadan önce taze telemetri şart,
körlemesine arm yok. Gevşeyen şey yalnızca **havadayken gazı kesme kararı**.

**Tek istemci kuralı.** `mini_ws` tek WebSocket istemcisi destekliyor. Eskiden
yeni gelen eskisini atıyordu; ikinci bir sekme/PWA açık kaldığında iki taraf
birbirini atıp duruyordu (ölçüm: saniyede ~148 kopuş), kumandanın loop'u
boğuluyor ve telsiz servisi aç kalıyordu. Artık **ilk gelen kazanır**: aktif
bir arayüz varken ikincisi reddedilir. Kaçış kapısı: mevcut istemci 3 sn hiç
veri göndermediyse ölü sayılıp yerini yenisine bırakır — sayfa yenilemesi ve
WiFi kopması bu yoldan geçiyor.

**ARD ve ACK payload — "servolar oynuyor ama telemetri yok" tuzağı:**
Tekrarlar arası bekleme (ARD) ACK **payload'ın havada geçirdiği süreden** uzun
olmak zorundadır. 250 kbps'te 8 byte'lık telemetri ACK'i ~550 µs, 13 byte'lık
kalibrasyon raporu ~710 µs sürer; üstüne alıcının RX→TX dönüşü (~130 µs) biner.
Eski ayar `setRetries(3, 5)` idi: ARD = 1000 µs, yani Nordic'in 250 kbps + ACK
payload için verdiği 1500 µs alt sınırın altında.

Sonuç sinsi bir arıza zinciri:

1. Paket uçağa **ilk denemede** ulaşır — servolar kolları takip eder.
2. Kumanda ACK'i beklemeyi erken bitirip paketi **tekrar** gönderir.
3. Uçağın telsizi tekrarı da ACK'ler ve her ACK, ACK payload FIFO'sundan
   (3 derinlik) bir yük daha **tüketir**.
4. Tüketim saniyede ~250'ye çıkar, üretim 60'ta kalır → FIFO sürekli boş →
   ACK'ler payload'sız döner.
5. Kumanda telemetri göremez, **ARM'ı reddeder** — oysa ileri yol kusursuz.

Aynı dengeyi uçak tarafı da bozabiliyordu: ACK payload'ı `paketIsle()` içinde,
**tekrar kontrolünden sonra** yükleniyordu. Aynı `seq` iki taşıma yolundan
geldiğinde ikinci kopya "tekrar" sayılıp atlıyor, ama nRF24 o kopyayı da ACK'leyip
bir yük tüketiyordu. Artık yük **tüketimin olduğu yerde** — `radioReceive()`
içinde, alınan her nRF24 paketi başına bir kez ve yalnızca FIFO boşsa —
yükleniyor: üretim ile tüketim birebir eşit.

Teşhis: kumandanın `[TX]` satırında `ack=N/s` alanı var. `ack` > 0 ama `rx=--`
ise ileri yol sağlam, **geri yol** ölüdür; kumanda bunu ayrıca bağıra bağıra
yazıyor. Uçağın `[RX]` satırındaki `tlm nrf=` / `red` sayacları hangi tarafın
yükleyemediğini söyler.

**Klon çip tuzağı:** ucuz nRF24 klonları (Si24R1 vb.) 250 kbps desteklemez.
`setDataRate()` sessizce başarısız olur, bir taraf 1 Mbps'te kalır, link tamamen ölür —
üstelik iki modül de "BAĞLI" görünür. Boot logunda `[RF] !! VERI HIZI AYARLANAMADI`
görürsen `rc_protocol.h`'da `RC_RF_DATARATE = 0` yap ve **iki projeyi de** yeniden yükle.

**Gönderim bloklamaz.** Kumanda `radio.write()` yerine `startWrite()` + `radio.update()`
ile STATUS yoklaması yapar. `write()` ACK gelene ya da tüm tekrarlar tükenene kadar bekler;
link koptuğunda bu 20 ms'lik bütçenin ~12 ms'sini yer — yani tam da kontrole en çok ihtiyaç
duyulan anda kumanda ağırlaşır. 15 ms'yi (`TX_TIMEOUT_US`) geçen gönderim iptal edilir;
logda `takilan=N` olarak görünür.

---

## 4. Paket formatı

Ortak tanımlar `include/rc_protocol.h` dosyasındadır ve **iki projede de aynı olmalıdır**.
Struct'lar `#pragma pack(1)` ile paketlenmiştir; ESP32'ler little-endian olduğu için
doğrudan `memcpy` uyumludur.

**Paket tipleri `magic` + boyut ikilisiyle ayırt edilir.** Sürüm 1'de hepsi `0xA5`'ti ve
sadece boyut bakılıyordu; kalibrasyon paketleri eklenince bu yetersiz kaldı.

| Tip | Yön | magic | Boyut |
|---|---|---|---|
| `RcPacket` | kumanda → uçak | `0xA5` | 10 |
| `RcTelemetry` | uçak → kumanda | `0x5A` | 8 |
| `RcConfigPacket` | kumanda → uçak | `0xC3` | 12 |
| `RcConfigReport` | uçak → kumanda | `0x3C` | 13 |

Boyutlar `static_assert` ile kilitli — bir alan eklersen derleme durur.

### 4.1 Kumanda → Uçak: `RcPacket` (10 byte)

| Offset | Alan | Tip | Açıklama |
|---|---|---|---|
| 0 | `magic` | u8 | `0xA5` |
| 1 | `seq` | u8 | Her pakette +1, 255→0 sarar (kayıp tespiti) |
| 2–3 | `ch[0]` **THROTTLE** | u16 | 1000 = stop … 2000 = tam gaz |
| 4–5 | `ch[1]` **ELEVATOR** | u16 | 1000 burun aşağı / 1500 nötr / 2000 yukarı |
| 6–7 | `ch[2]` **RUDDER** | u16 | 1000 sol / 1500 nötr / 2000 sağ |
| 8 | `flags` | u8 | bit0 = ARMED, bit1 = CALIB, üst nibble = sürüm (2) |
| 9 | `crc` | u8 | İlk 9 byte'ın CRC-8'i (poly 0x31, init 0xFF) |

Tüm kanallar mikrosaniye cinsindendir. **Aileron kanalı yoktur** — yatış rudder ile
veriliyor (polihedral kanat, klasik 3 kanallı eğitim uçağı düzeni).

### 4.2 Uçak → Kumanda: `RcTelemetry` (8 byte)

| Offset | Alan | Tip | Açıklama |
|---|---|---|---|
| 0 | `magic` | u8 | `0x5A` |
| 1 | `seqEcho` | u8 | Alınan son `RcPacket.seq` |
| 2–3 | `vbatMv` | u16 | Batarya mV. Ölçüm yoksa **0** |
| 4 | `lossPct` | u8 | Alıcının gördüğü paket kaybı % |
| 5 | `status` | u8 | bit0 armed, bit1 failsafe, bit2 kalibrasyon, bit3 kaydedilmemiş ayar |
| 6 | `rxHz` | u8 | Uçağın saniyede aldığı **benzersiz** paket sayısı |
| 7 | `crc` | u8 | |

`rxHz` sürüm 2'de eklendi: link kalitesi yüzdesi "kaç paket ulaştı"yı anlatmıyordu,
50 Hz'de 50 bekliyoruz ve sapma doğrudan görünüyor.

Telemetri hem ACK payload ile hem 100 ms'de bir bağımsız olarak gönderilir. Bağımsız
tazeleme şart: kumanda 1 sn içinde taze telemetri görmezse ARM'ı reddediyor, ve telemetri
yalnızca paket geldiğinde gönderilseydi tek bir boşluk bile "uçaktan cevap yok" demeye
yeterdi.

### 4.3 Kalibrasyon: `RcConfigPacket` (12) / `RcConfigReport` (13)

`RcConfigPacket`: `magic, seq, op, surf, minUs, midUs, maxUs, flags, crc`
`RcConfigReport`: `magic, ackSeq, surf, flags, minUs, midUs, maxUs, liveUs, crc`

`surf` (RcSurface): `0 = ELEVATOR`, `1 = RUDDER`, `2 = THROTTLE`.

**Gaz çıkışında alanlar farklı anlam taşır:**

| Alan | Yüzey | Gaz (`surf = 2`) |
|---|---|---|
| `minUs` | alt uç | ESC **stop** darbesi |
| `midUs` | **nötr** | **gaz tavanı** (uygulanacak en yüksek darbe) |
| `maxUs` | üst uç | ESC **tam gaz** darbesi |

`op` (RcCfgOp): `1 ENTER`, `2 EXIT`, `3 SET`, `4 TEST`, `5 SWEEP`, `6 CENTER`, `7 SAVE`,
`8 LOAD`, `9 DEFAULT`, `10 READ`, `11 ESC_HI`, `12 ESC_LO`.

`RC_CFG_TEST`'te `midUs` alanı ham darbe değeri taşır (uç nokta kontrolü için).

**Güvenilirlik:** kumanda komutu, uçaktan `ackSeq` eşleşen rapor gelene kadar 60 ms'de bir
tekrarlar; 1.5 sn'de onay gelmezse arayüzde hata gösterir. Uçak tarafında aynı `seq`
3 saniye içinde tekrar gelirse kopya sayılır ve **uygulanmaz** (yalnız rapor yeniden
gönderilir) — yoksa `SAVE` gibi komutlar birden çok kez çalışırdı. Süre sınırı, kumanda
resetlendiğinde `seq` sayacının 1'den başlaması durumunu da çözer.

`RcConfigReport.liveUs` o çıkışa **o an yazılan gerçek darbe**yi taşır. Arayüzdeki
değerlerin kaynağı budur: ekranda gördüğün şey uçağın uyguladığı ayardır, kumandanın
gönderdiği değil.

---

## 5. Servo kalibrasyonu

Servo yönü, nötrü ve uç noktaları artık derleme sabiti değil: kalibrasyon modundan
ayarlanıp uçağın **NVS'ine** yazılıyor. Kart resetlense de kalıyor, uçtaki kartta USB
olmadan da değiştirilebiliyor.

### Eşleme matematiği

Endüstri standardı **end point / travel adjust** davranışı — nötrün iki yanında
**bağımsız** ölçekleme:

```
giriş > 1500  →  midUs .. maxUs   arasına ölçeklenir
giriş < 1500  →  minUs .. midUs   arasına ölçeklenir
```

Bir yöne %100, diğerine %70 hareket verebilirsin; mekanik linkajlar hiçbir zaman simetrik
değildir. Yön terslemesi ölçeklemeden **önce**, nötr etrafında aynalanarak yapılır — ters
çevirmek uç noktaları birbirine karıştırmaz.

Gaz: `1000..2000 → stop..tam gaz`, sonra **tavan** ile kırpılır.

### Güvenlik kuralları

| Kural | Nerede zorlanıyor |
|---|---|
| Kalibrasyona yalnızca DISARM iken girilir | Uçak, `RC_CFG_ENTER` |
| Kalibrasyon modunda ARM **imkânsız** | Uçak (`armed = ... && !kalibModu`) ve kumanda |
| Kalibrasyon modunda ESC her zaman stop | Uçak, `escYaz()` |
| `TEST`/`SWEEP` gaz çıkışına uygulanmaz | Uçak, `konfigIsle()` |
| Her çıkış `900..2100 µs` ile kırpılır | Uçak, `cikisYaz()` → `rcClampHard()` |
| Geçersiz ayar reddedilir (sıralama, ≥50 µs hareket) | Uçak, `ayarGecerli()` |
| `TEST` 4 sn sonra kendiliğinden nötre döner | Uçak, `kalibTick()` |
| Link koparsa kalibrasyon modundan çıkılır | Uçak, `failsafeUygula()` |
| Bozuk NVS kaydı → fabrika ayarı | Uçak, `ayarYukle()` (imza + geçerlilik) |

`TEST`'in zaman aşımlı olması önemli: servo bir uç noktada dayanağa dayanırsa akım çeker
ve ısınır. Her yeni `TEST` sayacı sıfırlar, yani slider'ı çevirirken servo istediğin
noktada durur.

### ESC gaz aralığı kalibrasyonu

ESC, kalibrasyon sırasında gördüğü **en geniş** darbeyi "tam gaz", **en dar** darbeyi
"stop" olarak öğrenir. Kalibre edilmemiş bir ESC'de 1200 µs hâlâ stop bölgesinde kalabilir
ve motor hiç dönmez — *"gaz gidiyor ama motor dönmüyor"* şikâyetinin en sık sebebi budur.

İki yol var:

1. **Seri port (USB bağlıyken):** boot'ta 5 saniye içinde `k` bas, adımları takip et.
2. **Arayüzden:** Ayarlar → ESC gaz aralığı kalibrasyonu. "Pervaneyi söktüm" kutusunu
   işaretlemeden butonlar açılmaz; uçak tarafı da `RC_CFGF_PROP_OFF` bitini arar ve
   kalibrasyon modunda + DISARM değilse reddeder. 1. adımda unutulursa 30 sn sonra
   kendiliğinden stop'a döner.

**Her iki yolda da pervane sökülü olmalı.** Arayüz yolunda uçak kartı USB'den beslenmeli,
LiPo yalnızca ESC'ye gitmeli.

---

## 6. Failsafe ve arm zinciri

| Nerede | Koşul | Sonuç |
|---|---|---|
| Uçak | 500 ms (`RC_FAILSAFE_MS`) paket gelmedi | ESC → stop, yüzeyler → **kalibre edilmiş** nötr, armed = false, arm kilidi takılır |
| Uçak | CRC / magic / sürüm hatalı | Paket sessizce atılır, `ardisikGecerli` sıfırlanır |
| Uçak | Link geri geldi | **10 ardışık** geçerli paket (`RELINK_PAKET`) beklenir |
| Uçak | Boot ve her failsafe sonrası | **Arm kilidi** takılı: kumandadan `ARMED=0` görülmeden arm olmaz |
| Kumanda | Tarayıcı 1 sn komut göndermedi | Otomatik DISARM |
| Kumanda | Uçaktan 1 sn telemetri yok | Otomatik DISARM |
| Kumanda | Gaz kolu minimumda değilken ARM | Reddedilir |
| Kumanda | Uçak kalibrasyon modunda iken ARM | Reddedilir |
| Kumanda | ACİL butonu / boşluk tuşu | Anında DISARM + nötr |
| Tarayıcı | Sayfa arka plana alındı | Gaz 0, yüzeyler nötr, DISARM |

**Failsafe nötrü 1500 değil, `ayar[].midUs`.** Linkaj kaymışsa failsafe konumu da kaymış
olurdu; kalibre edilmiş nötre gitmek doğru olan.

**Arm kilidi neden var:** link bir an kesilip geri geldiğinde uçak kendiliğinden arm
olmamalı. Kilit ancak kumandadan `ARMED=0` bir paket görüldüğünde açılır — yani operatör
DISARM → ARM yapmadan motor dönmez.

> **KUMANDA DURUMU ≠ UÇAK DURUMU.** İkisi arayüzde ayrı gösterilir. Kumanda "ARMED"
> derken uçak "DISARM" diyebilir — o zaman uçakta arm kilidi açılmamıştır; DISARM'a basıp
> tekrar ARM etmek gerekir.

---

## 7. Kumanda arayüzü

WiFi erişim noktası — internete gerek yok, telefondan/laptoptan bağlan:

- **SSID:** `RC-Plane-TX`  **Şifre:** `rcplane1234`  **Adres:** `http://192.168.4.1`

### Taşıma: WebSocket (birincil) + HTTP (yedek)

Kol verisi **WebSocket** (port 81) üzerinden 20 Hz gider. `WebServer` her cevaba
`Connection: close` koyuyor ve tek istemciyi seri işliyor; 20 Hz'de bu her komut için yeni
bir TCP el sıkışması demek ve gecikme dalgalanıyor. WebSocket'te bağlantı bir kez kuruluyor.

WebSocket sunucusu `include/mini_ws.h` içinde, **kütüphanesiz** (SHA-1 ve base64 dahil).
Uçuşa hazır bir firmware'in derlemesi internete bağlı olmamalı. Tarayıcı WebSocket
kuramazsa sayfa otomatik olarak `/c` HTTP yoluna düşer.

| Endpoint | Açıklama |
|---|---|
| `GET /` | Arayüz sayfası |
| WS `:81` `C<gaz>,<ele>,<rud>,<arm>` | Kol konumları (gaz 0..1000, yüzeyler −1000..1000) |
| WS `:81` `X` | Acil durdurma |
| WS `:81` `S<anahtar>=<değer>` | Pilot ayarı |
| WS `:81` `K<op>,<surf>,<mn>,<md>,<mx>,<f>` | Kalibrasyon komutu |
| WS `:81` `G` | Ayarları ve raporları iste |
| `GET /c?t=&e=&r=&arm=` | HTTP yedek yolu, durum JSON'u döner |
| `GET /status` | Durum + pilot ayarları + kalibrasyon raporları |
| `GET /stop`, `/set?k=&v=`, `/cfg?op=&s=&...` | HTTP yedek yolu |

`C` mesajı aynı zamanda **watchdog beslemesidir** — sayfa kapanır ya da WiFi koparsa
kumanda 1 sn içinde DISARM olur, uçak da 500 ms sonra failsafe'e girer.

### Kol düzeni

İki gimbal (kol yuvası), tıpkı fiziksel bir vericide olduğu gibi. Üç düzen var; uçak
3 kanallı olduğu için aileron ekseni her düzende boş kalıyor, değişen şey **boş eksenin
yeri**:

| | Sol kol | Sağ kol |
|---|---|---|
| **Mod 1** | rudder (yatay) + elevator (dikey) | gaz (dikey) |
| **Mod 2** *(varsayılan)* | rudder (yatay) + gaz (dikey) | elevator (dikey) |
| **3 Kanal** | yalnızca gaz (dikey) | rudder (yatay) + elevator (dikey) |

Mod 2 simülatör/dünya standardı. **3 Kanal** düzeni, gerçek vericide rudder'ı aileron
kanalına alıp iki yüzeyi de sağ kola toplama alışkanlığının karşılığı — sol kol saf gaz
kolu olur. Boş eksen ekranda soluk çizgiyle ve `KILITLI` etiketiyle gösteriliyor.

Geçersiz bir mod değeri her zaman 2'ye düşer: bilinmeyen bir mod, kolların hangi kanalı
sürdüğünün belirsiz olması demek olurdu.

**Yerleşim:** kollar **ekranın alt köşelerinde**, kenar uzunluğu
`clamp(140px, min(34vw,46vh), 300px)` — yani hiçbir ekranda 140 dp'nin altına inmiyor.
Arayüz yatay ekran için tasarlandı; dikeyde orta sütun kolların üstüne alınır ve bir uyarı
şeridi çıkar, ama **kontrol kesilmez** — uçuş sırasında telefon dönünce kolların
kaybolması kabul edilemez.

**Yaylı vs yaysız:** elevator ve rudder bırakılınca nötre döner (gerçek kumandadaki yay);
gaz kolu bulunduğu yerde kalır (gerçek kumandadaki tırtıl).

Bırakıldığında yaylı eksenler nötre gider, gaz yerinde kalır.

### Bağlı (anchored) kol modeli

**Dokunmak komut değil.** Parmağın değdiği an, kolun *o anki değeri* o noktaya sabitlenir;
kanalı değiştiren şey dokunuştan **sonraki** harekettir. Parmağın yuvanın neresine indiği
önemsiz.

Önce mutlak eşleme vardı — kolun konumu doğrudan kanal değeriydi. İki kusuru vardı ve
ikincisi uçuş güvenliğini ilgilendiriyor:

1. Kolu tutmak için tam ortasına basmak gerekiyordu; isabet edilemeyince kol parmağın
   düştüğü yere **zıplıyordu**.
2. Uçuşta ele çarpan bir parmak, yüzeyi bir anda tam sapmaya götürüyordu.

Bağlı modelde çarpma yalnızca bir referans noktası belirler, hiçbir kanal kıpırdamaz.

**Origin push** — bu modelin bilinen tuzağı ve çözümü. Referans sabit kalsaydı, yuvanın
tepesinden tutup daha yukarı çekmek mümkün olmaz, tam sapmaya tek hamlede ulaşılamazdı.
Sınır aşıldığında *taban değeri* kaydırılarak parmak hep anlamlı kalır: nereden tutarsan tut
tam sapmaya ulaşırsın ve geri çekince değer **anında** düşer, doyuma yapışıp kalmaz. Tam
sapmadayken yuva kenarlığı sarıya döner.

**Ölçek:** 100 px parmak hareketi = kanal genişliğinin yarısı. Yüzeylerde ortadan kenara
tam sapma, gazda dipten tepeye %0→%100 — ikisi de uçtan uca aynı yolu kat eder, tıpkı
fiziksel bir gimbalde olduğu gibi. Kaldırıp yeniden tutmak birikimlidir.

**Çoklu dokunma** destekli: her gimbal kendi `pointerId`'sini yakalar
(`setPointerCapture`), böylece "bırakma" ile "dışarı taşma" birbirine karışmaz ve iki kol
aynı anda kullanılabilir. Aynı yuvadaki ikinci parmak yok sayılır.

**Gecikme.** Kol verisi zamanlayıcıyla değil, **dokunma olayının kendisinde** gönderilir
(en fazla 10 ms'de bir; 120 Hz dokunmatik örneklemede WebSocket'i boğmamak için).
Arayüz tarafında tamponlama yok — toplam gecikme pratikte telsizin 20 ms'lik çerçeve
periyodundan ibaret. Ayrıca 50 ms'de bir keepalive gider; watchdog beslemesi odur.

**Titreşim:** ARM, DISARM, failsafe'e giriş ve basılı-tut onayının tamamlanmasında
`navigator.vibrate()`. Failsafe titreşimi yalnızca durum *değiştiğinde* tetiklenir.

### Kazara dokunmaya karşı

Uçuş sırasında el bir yere çarpar. Alınan kararlar:

| Risk | Karar |
|---|---|
| Ele çarpan parmak yüzeyi savurur | Bağlı kol modeli — dokunmak kanalı değiştirmez |
| Avuç + başparmak aynı yuvada çakışır | Aynı yuvadaki ikinci `pointerId` yok sayılır |
| Yuva dışına dokunma | Kolların dışında hiçbir dokunuş kanal sürmez |
| Ele çarpan ARM/ACİL tuşu | **Basılı tutma** ister (ARM 600 ms, ACİL 400 ms); parmak 44 px kayarsa onay iptal |
| AYAR ekranı uçuşta açılır, kolları kapatır | ARMED iken AYAR tuşu kilitli |
| Geri hareketi / uzun basma menüsü | Yutulur (`popstate` + `contextmenu`) |
| Kazara yenileme | ARMED iken tarayıcı onay sorar (`beforeunload`) |
| Sistem kenar hareketi kola değer | Kollar kenardan 16 px içeride |
| URL çubuğu / kenar hareketleri | İlk dokunuşta tam ekran + yatay kilit denenir |

Acil durdurmanın basılı tutma istemesi bilinçli: ele çarpan bir parmağın motoru kesip
zorunlu inişe sokması, gerçek bir acil durumda 400 ms beklemekten çok daha pahalı.

**Ekran kilidi ve bildirimler uçuşu kesmez.** Wake Lock ile ekran açık tutulur; bildirim
gölgesi açıldığında (`blur`) hiçbir kanal değişmez. Uygulama gerçekten arka plana atılırsa
tarayıcı zamanlayıcıları kıstığı için kumandanın 1 sn'lik watchdog'u zaten devreye girer —
korumayı oraya bırakmak, geçici bir bildirimi ölümcül yapmaktan iyi.

**Uçuş ekranında animasyon, geçiş efekti, gradyan ve gölge yok.** Her piksel ya bir değer
gösteriyor ya bir kontrol. Renkler güneş altında okunacak şekilde seçildi: en sönük etiket
bile zemine karşı ~11:1 kontrastta, değerler ~18:1.

**Gamepad:** tarayıcının Gamepad API'si açıksa gerçek bir joystick ya da USB moduna
alınmış bir RC kumandası doğrudan kullanılabilir (%8 ölü bölge).

**Klavye (tezgâh testi):** `W`/`S` gaz, oklar elevator, `A`/`D` rudder, `Boşluk` acil
durdurma, `X` gaz kes.

### Pilot ayarları (kumanda NVS'inde)

| Ayar | Aralık | Varsayılan |
|---|---|---|
| Kol modu | 1 / 2 / 3 (3 kanal) | 2 |
| Trim (gaz / ele / rud) | ±200 µs = kanalın **±%20**'si | 0 |
| Expo (ele / rud) | 0–50 % | 25 |
| Oran / dual rate | 30–100 % | 100 |
| Gaz sınırı | 20–100 % | 100 |

Trim uçuş ekranındaki `+`/`−` tuşlarından 5 µs adımlarla ayarlanır.

**Gaz trim'i ve ARM kapısı.** Pozitif gaz trim'i, kol tam aşağıdayken bile ESC'ye stop'tan
büyük bir darbe gönderir — yani arm edildiği anda motor döner. Özelliği kırpmak yerine arm
kapısını trim'e duyarlı hale getirdik: ARM kararı kolun konumuna değil **gerçekten
gönderilecek darbeye** bakıyor. Pozitif trim varken arm etmek mümkün değil, özellik ise
olduğu gibi duruyor.

**Gaz kanalında ters çevirme bilerek yok.** Ters gaz, kol aşağıdayken tam gaz demek olurdu;
yüzeylerde anlamlı olan bu ayarın gaz kanalında karşılığı bir arıza modu.

Expo formülü endüstri standardı: `y = x · ((1−e) + e·x²)`. Nötrün etrafını yumuşatır,
uç noktalarda tam yetkiyi korur. İlk uçuşlarda %25 civarı kolun aşırı hassas olmasını
engelliyor.

**Gaz iki kademe sınırlı:** kumandadaki `thrLimit` ve uçaktaki `midUs` tavanı birbirinden
bağımsız; ikisinden düşük olan geçerlidir.

### Kalkış öncesi kontrol

Ayarlar ekranındaki liste, ARM'ı engelleyen şeyi tek bakışta gösterir: telsiz yolu,
telemetri, link ≥ %50, failsafe yok, gaz minimumda, kalibrasyon modu kapalı, kalibrasyon
kaydedilmiş.

---

## 8. İlk çalıştırma sırası

1. **Pervaneyi sök.**
2. `flight_software`'i yükle (`pio run -t upload -t monitor`). Boot logunda LEDC
   kanallarının kurulduğunu ve reset sebebinin `POWERON` olduğunu doğrula.
3. Kumandayı yükle, telefonla `RC-Plane-TX`'e bağlan, `192.168.4.1`'i aç.
4. `LINK` %90+, `UCAK RX` ~50 Hz olmalı. Düşükse: anten yönü (iki modülün
   anteni birbirine paralel; uç uça bakan PCB anten en kötü yön), nRF24'ü
   ESP32'nin anteninden uzaklaştır, modül bacağında 10–100 µF + 100 nF.
   Üst şeritteki link etiketi bağlantının **hangi yolla** sağlandığını yazıyor
   (`nRF24`, `NOW`, `nRF24+NOW`).
5. **Servo kalibrasyonu** (motor kapalı):
   Ayarlar → KALIBRASYONA GIR → her yüzey için yön, nötr, uç noktalar → `TARA` ile
   dayanağa vurmadığını doğrula → **UÇAĞA KAYDET** → ÇIK.
6. Kolları oynat, yüzeylerin doğru yöne gittiğini kontrol et
   (elevator kolu yukarı → burun yukarı; rudder sağa → uçak sağa).
7. Gerekiyorsa ESC gaz aralığı kalibrasyonu (bkz. §5).
8. ARM et, gazı çok az aç, motor yönünü kontrol et.
9. İlk uçuş için: gaz sınırı %70–80, expo %25–30, oran %70. Güvendikçe aç.

---

## 9. Değiştirmek isteyebileceğin sabitler

| Sabit | Yer | Varsayılan |
|---|---|---|
| `TEZGAH_MODU` | controller `src/main.cpp` | **false** (uçuş) |
| `AP_SSID` / `AP_PASS` | controller `src/main.cpp` | RC-Plane-TX / rcplane1234 |
| `AP_CHANNEL` | controller `src/main.cpp` | 1 |
| `RF_SPI_HZ` | her iki `src/main.cpp` | 4000000 |
| `TLM_TIMEOUT_MS` | controller `src/main.cpp` | 1000 |
| `PIN_ESC` / `PIN_RUDDER` / `PIN_ELEVATOR` | flight `src/main.cpp` | 0 / 3 / 4 |
| `RELINK_PAKET` | flight `src/main.cpp` | 10 |
| `KALIB_TEST_MS` | flight `src/main.cpp` | 4000 |
| `RC_RF_CHANNEL` | `rc_protocol.h` | 108 |
| `RC_RF_ADDRESS` | `rc_protocol.h` | "RCP01" |
| `RC_RF_DATARATE` | `rc_protocol.h` | 2 (250 kbps) |
| `RC_TX_PERIOD_MS` | `rc_protocol.h` | 20 (50 Hz) |
| `RC_FAILSAFE_MS` | `rc_protocol.h` | 500 |

Gaz tavanı ve servo uç noktaları **artık sabit değil** — arayüzden ayarlanıyor.

---

## 10. Seri log okuma

### Uçak (`[RX]` satırı)

```
[RX] nrf=BAGLI now=BAGLI | DISARM rxarm=0 kilit=ACIK relink=0/10 |
     thr=1000<-1000(disarm) ele=1500->1500 rud=1500->1500 |
     50 paket, tekrar 50, kayip %0, bozuk 0 | tlm nrf=50/red0 now=50/hata0
```

| Alan | Anlamı |
|---|---|
| `rxarm` | Kumandadan gelen ARMED bitinin ham hali |
| `kilit` | Arm kilidi. `KAPALI` iken ARMED gelse bile arm olmaz |
| `thr=A<-B(sebep)` | A uygulanan, B kumandanın istediği, sebep neden kırpıldı |
| `ele=A->B` | A kumandadan gelen, B kalibrasyondan sonra çıkışa yazılan |
| `tekrar` | İkinci taşıma yolundan gelen kopya sayısı (normal, kayıp değil) |

*"Gaz gidiyor ama motor dönmüyor"* derdinde `thr=1000<-1600(disarm)` yazıyorsa sorun
kumandada değil, arm kapısında.

### Kumanda (`[TX]` satırı)

```
[TX] nrf=BAGLI now=BAGLI ws=VAR | web=20/s | kumanda=DISARM ucak=DISARM
     thr=1000 ele=1500 rud=1500 | link=98% | rx=OK 50Hz kayip=%0 vbat=0mV
```

`web=0/s` görüyorsan sorun telsizde değil, tarayıcıda — sayfa istek göndermiyor.
`ws=yok` ise WebSocket kurulamamış, HTTP yedek yolu çalışıyor demektir.

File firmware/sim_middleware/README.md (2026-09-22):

# sim_middleware — RC arayüzü → vJoy köprüsü

Telefondaki RC kumanda web arayüzünü, bilgisayardaki uçuş simülatörleri
(RealFlight Evo, Velocidrone, FPV.SkyDive…) için **sanal bir USB joystick'e**
çevirir. Simülatör karşısında gerçek bir kumanda görür; senin arayüzün
olduğunu bilmez.

---

## 1. Amaç — bu şey ne işe yarıyor?

Uçağı kırmadan önce üç şeyi denemek gerekiyor:

**Kumanda arayüzünün kendisini denemek.** `controller_software` içindeki web
arayüzü klasik bir kumanda değil: telefon ekranında, bağlı (anchored) kol
modeliyle çalışıyor. Bu modelin gerçekten uçurulabilir olup olmadığı ancak
uçarken anlaşılır. Uçağı havaya atıp öğrenmek pahalı bir yol.

**Kas hafızası kurmak.** Expo, oran, gaz sınırı, mod seçimi — hepsi
arayüzde ayarlanabiliyor. Hangi değerlerin sana oturduğunu simülatörde
saatlerce, bedavaya deneyebilirsin.

**Arayüz değişikliklerini regresyona sokmak.** Kol eğrisini ya da gönderim
hızını değiştirdiğinde "daha mı iyi oldu" sorusunun cevabı laboratuvarda
değil, uçarken belli oluyor. Simülatör bunu tekrarlanabilir hale getiriyor.

Bu köprü olmadan arayüzü test etmenin tek yolu gerçek uçuş. Köprüyle
birlikte, **gerçek uçuşta kullanacağın arayüzün tam kendisiyle** simülatörde
uçuyorsun — ayrı bir "test arayüzü" yok, dolayısıyla test ettiğin şeyle
uçtuğun şey birebir aynı.

---

## 2. Mantık — nasıl çalışıyor?

### Veri akışı

```
  TELEFON                              BILGISAYAR
┌───────────────────────┐            ┌──────────────────────────────────┐
│  web arayuzu          │            │  app.py                          │
│  (slider / kol)       │            │                                  │
│         │             │            │   on_rc()                        │
│         ▼ oninput     │            │      │                           │
│  simSetAxes(...)      │            │      ▼                           │
│         │             │            │   us_to_vjoy()   1000-2000 us    │
│         ▼             │            │      │           →   0-32767     │
│  volatile.emit("rc",  │            │      ▼                           │
│    [ail,ele,thr,rud]) │            │   UpdateVJD()  tek HID raporu    │
└─────────┬─────────────┘            └──────┬───────────────────────────┘
          │ WebSocket                       │
          │ localhost:5000                  ▼
          │                            ┌─────────────┐
          └──── adb reverse ──USB──────│ vJoy surucu │
                                       └──────┬──────┘
                                              │ sanal USB joystick
                                              ▼
                                       ┌─────────────┐
                                       │ RealFlight  │
                                       └─────────────┘
```

### Dört tasarım kararı ve gerekçeleri

**Neden `adb reverse`, neden Wi-Fi değil?**
Wi-Fi üzerinden gitseydik araya router, kanal çakışması ve değişken gecikme
girerdi — üstelik ölçmesi zor bir gecikme. `adb reverse tcp:5000 tcp:5000`
telefonun `localhost:5000` portunu USB kablosu üzerinden PC'nin
`localhost:5000` portuna bağlıyor. Trafik hiç kablosuz ortama çıkmıyor.
Ölçülen gidiş-dönüş: **~2 ms**. Ayrıca uçuş alanında router yok; USB her
zaman var.

**Neden vJoy?**
Simülatörler HID joystick'i işletim sistemi seviyesinde okuyor. Simülatöre
"dışarıdan komut enjekte etme" gibi bir yol yok — olsa bile her simülatör
için ayrı iş olurdu. vJoy sahte bir HID cihazı yaratıyor; RealFlight,
Velocidrone, hepsi bunu normal bir kumanda sanıyor. Tek köprü, bütün
simülatörler.

**Neden 1000-2000 µs?**
Arayüz zaten RC dünyasının birimini üretiyor: servo darbe genişliği.
Gerçek uçuşta bu değer telsizden uçağa gidiyor. Simülatöre giderken de
aynı değeri kullanıyoruz ki **test ettiğin sinyal, uçtuğun sinyalle aynı
olsun**. Dönüşüm bu köprünün son adımında, tek bir fonksiyonda yapılıyor:

```
1000 us  →      0     (eksen dibi)
1500 us  →  16384     (notr)
2000 us  →  32767     (eksen tepesi)
```

Aralık dışı değerler **eşlemeden önce** kırpılıyor. Bozuk tek bir paket
simülatörde tam sapmaya yol açmasın diye.

**Neden değişim anında gönderim, neden sabit 50 Hz değil?**
Sabit periyotlu bir `setInterval`, kolun hareketiyle paketin çıkışı arasına
en kötü halde bir tam periyot koyar. Gönderimi dokunma olayının kendisi
tetikliyor; 10 ms'lik taban yalnızca 120 Hz örnekleyen bir dokunmatikte
bağlantıyı boğmamak için. Bekleyen bir değişiklik kalırsa bir sonraki tik
onu boşaltıyor. (Aynı model `web_ui.h` içindeki `kanalGonder()`'de de var.)

### Gecikme bütçesi

| Aşama | Süre |
|---|---|
| dokunma → `oninput` | tarayıcıya bağlı, ~8-16 ms |
| gönderim tabanı (`MIN_GAP_MS`) | 0-10 ms |
| WebSocket + adb + USB | ~1 ms |
| `on_rc` → `us_to_vjoy` → `UpdateVJD` | ~30 µs |
| vJoy sürücü → simülatör | 1 HID kare |

Yani toplam gecikmenin neredeyse tamamı ekranda ve tarayıcıda; köprü
ölçülebilir bir şey eklemiyor. Bunu korumak için yapılanlar:

- Paket geldiği anda vJoy'a yazılıyor; arada kuyruk, zamanlayıcı ya da
  "60 Hz'e düşür" katmanı **yok**.
- Sıcak yolda (`on_rc`) log, print, string formatlama, sözlük kopyalama
  yok. Sayaçlar biriktirilip watchdog thread'inde basılıyor.
- İstemciye ack dönülmüyor → paket başına fazladan TCP gidiş-dönüşü yok.
- Nagle kapalı (`disable_nagle_algorithm`); açık kalsa birkaç baytlık
  paketler için 40 ms'ye varan bekleme görülebiliyor.
- İstemci `transports:["websocket"]` ile bağlanıyor: uzun yoklama
  (polling) aşaması hiç yaşanmıyor, ilk paket bile WebSocket üzerinden.
- `volatile.emit`: bağlantı koptuğunda paketler kuyruğa girmiyor. RC'de
  en son değer dışındaki her şey çöp; kuyruk geri geldiğinde saniyeler
  öncesinin kol pozisyonlarını boşaltmasın.
- Werkzeug istek logu kapalı — Windows'ta konsola yazmak pahalı.
- `async_mode="threading"` + `simple-websocket`: eventlet/gevent
  monkey-patch'i olmadan gerçek WebSocket. (eventlet Python 3.11+ ile
  sorun çıkarıyor.)

### Failsafe

**500 ms** paket gelmezse — telefon kilitlendi, tarayıcı arka plana atıldı,
USB çıktı — gaz kesilir, diğer eksenler nötre döner. Bağlantı koptuğunda
(`disconnect`) aynısı anında uygulanır. Simülatörde tam gazda kalıp
duvara girmemek için.

Bunu yapan tek yardımcı thread `_watchdog()`; sıcak yoldan uzak duruyor,
50 ms'de bir uyanıyor ve ikinci işi olarak Hz sayacını basıyor.

---

## 3. Kurulum

### Bir kerelik

**a) Python paketleri**

```
pip install flask flask-socketio simple-websocket pyvjoy
```

`simple-websocket` şart: `async_mode="threading"` ile gerçek WebSocket'i o
sağlıyor.

> Bu klasörde hazır bir `.venv` var. Global Python'a bulaşmak istemezsen
> doğrudan onu kullan: `.venv\Scripts\python.exe app.py`

**b) vJoy sürücüsü**

[vJoy](https://sourceforge.net/projects/vjoystick/) kur — 64-bit Python
kullanıyorsan 64-bit sürüm. Sonra `vJoyConf`'u aç:

- Device 1 → **Enable**
- Eksenler: **X, Y, Z, Rz** işaretli olsun
- Buton/POV sayısı önemsiz

**c) Socket.IO istemci kütüphanesi**

```
python tools/fetch_client.py
```

CDN'den bir kez indirip `static/vendor/` içine koyar. Telefonda internet
olmayabilir (uçuş alanında genelde yok, sayfa da ESP32'den geliyor
olabilir) — kütüphane PC'de dursun, telefona USB üzerinden servis edilsin.

### Her seferinde

```
python app.py
```

```
adb reverse tcp:5000 tcp:5000
```

(Telefonda USB hata ayıklama açık olmalı. `adb reverse --list` ile
kontrol edebilirsin.)

---

## 4. Test — kademeli doğrulama

Sorun çıktığında hangi katmanda olduğunu bilmek için sırayla ilerle.
Her adım bir öncekini varsayar.

### Adım 1 — vJoy olmadan, köprünün mantığı

```
python app.py --dry-run          # bir konsolda
python tools/selftest.py         # baska bir konsolda
```

Eşleme değerlerini, 100 Hz akışı, gidiş-dönüş gecikmesini ve failsafe'i
kontrol eder. Beklenen çıktı:

```
1) esleme
  1000 us                      0            OK
  1500 us                      16384        OK
  2000 us                      32767        OK
  1250 us                      8192         OK
  900 us (kirpma)              0            OK
  2400 us (kirpma)             32767        OK
  1500 us ters                 16383        OK
  1000 us ters                 32767        OK

2) akis
  bagli, transport: websocket
  300 paket / 3.00 s  ->  100 Hz gonderildi
  sunucuya ulasan              300          OK

3) gidis-donus
  ortanca 2.23 ms   en kotu 3.09 ms

4) failsafe
  akis varken                  False        OK
  800 ms sessizlik sonrasi     True         OK

HEPSI GECTI
```

Burada takılıyorsan sorun Python tarafında; vJoy'a hiç bakma.

### Adım 2 — vJoy'a gerçekten yazıyor mu?

```
python app.py
```

Konsolda `vJoy cihaz 1 alindi (UpdateVJD yolu)` görmelisin. Sonra
tarayıcıda (PC'de, telefona gerek yok):

```
http://localhost:5000
```

4 slider'lı test paneli açılır. Yanına **vJoy Monitor**'ü aç (vJoy ile
birlikte gelir) ve slider'ları oynat. Eksenler kıpırdamalı:

| Slider | vJoy Monitor'da |
|---|---|
| AIL | X |
| ELE | Y |
| THR | Z |
| RUD | Rz |

Windows'un kendi `joy.cpl` penceresi de iş görür (Çalıştır → `joy.cpl` →
vJoy Device → Özellikler).

### Adım 3 — telefon bağlantısı

Telefonu USB ile bağla, `adb reverse tcp:5000 tcp:5000` çalıştır, telefonun
tarayıcısında `http://localhost:5000` aç. Aynı test paneli telefonda
açılmalı, slider'lar PC'deki vJoy eksenlerini oynatmalı.

Bağlantı durumu sayfanın üstünde: yeşil **bağlı** / kırmızı **kopuk**.
`simPing()` butonu konsola gidiş-dönüş gecikmesini yazar.

### Adım 4 — simülatör

1. `app.py` çalışırken RealFlight'ı aç (vJoy cihazı önceden görünsün).
2. **Simulation → Select Controller → vJoy Device**
3. **Calibrate**: her ekseni uçtan uca gezdir — test panelindeki
   slider'ları kullanmak en kolayı.
4. **Channel mapping**: Aileron→X, Elevator→Y, Throttle→Z, Rudder→Rz.
5. Uç.

### Sürekli izleme

Sunucu konsolu 2 saniyede bir paket hızını basıyor:

```
15:43:17  96 Hz  (191 paket / 2 s)
```

Anlık durum: `http://localhost:5000/health`

```json
{"vjoy":"device 1","failsafe":false,"packets":12480,"age_ms":11}
```

`age_ms` son paketin üstünden geçen süre. 500'ü aşarsa `failsafe` true olur.

---

## 5. Kullanım — kendi arayüzüne bağlama

Sayfaya iki script ekle:

```html
<script src="http://localhost:5000/socket.io.min.js"></script>
<script src="http://localhost:5000/static/rc_sim_client.js"></script>
```

Adresin mutlak olması şart: sayfa ESP32'den servis ediliyorsa `localhost`
telefonun kendisi, oradan da adb ile PC'ye düşüyor.

Slider'ın `oninput`'unda tek satır:

```js
simSetAxes({ ail: 1500, ele: 1500, thr: 1000, rud: 1500 });
```

Verilen kanallar güncellenir, verilmeyenler son değerinde kalır. Yani tek
bir slider için `simSetAxes({ ail: +s.value })` yeterli.

Diğer yardımcılar ([static/rc_sim_client.js](static/rc_sim_client.js)):

| | |
|---|---|
| `simPing()` | gidiş-dönüş gecikmesini konsola yazar |
| `simOnState(ok)` | sen tanımlarsan bağlantı durumu değişince çağrılır |
| `simFromStick(stick)` | aşağıya bak |

### Mevcut ESP32 kumanda arayüzü için

`controller_software/include/web_ui.h` içindeki kol modeli µs değil kendi
birimini tutuyor (`thr 0..1000`, `ele/rud -1000..1000`). O arayüze
simülatör desteği eklemek için `kanalGonder()` içine tek satır yeter:

```js
simFromStick(stick);          // 0..1000 / -1000..1000  ->  1000..2000 us
```

O arayüzde **aileron kanalı yok** (3 kanal uçak). Simülatörde kanadın da
eğilmesini istersen `app.py` içinde:

```python
MIRROR_RUDDER_TO_AILERON = True
```

Rudder aynı anda aileron eksenine de yazılır.

---

## 6. Eksen eşlemesi (Mode 2)

| Kanal | Kumanda | vJoy ekseni | pyvjoy sabiti | struct alanı |
|---|---|---|---|---|
| `ail` | sağ çubuk X | X | `HID_USAGE_X` | `wAxisX` |
| `ele` | sağ çubuk Y | Y | `HID_USAGE_Y` | `wAxisY` |
| `thr` | sol çubuk Y | Z | `HID_USAGE_Z` | `wAxisZ` |
| `rud` | sol çubuk X | RZ | `HID_USAGE_RZ` | `wAxisZRot` |
| `aux1`| — | RX | `HID_USAGE_RX` | `wAxisXRot` |
| `aux2`| — | RY | `HID_USAGE_RY` | `wAxisYRot` |

Eşleme `app.py` içinde `AXES` demetinde, tek yerde tanımlı.

**İki yazma yolu var.** Varsayılan `USE_BATCH_UPDATE = True`: dört ekseni
tek bir HID raporunda (`UpdateVJD`) yazar. Hem tek DLL çağrısı, hem de
eksenler aynı karede güncellendiği için aralarında yırtılma olmaz.
`False` yaparsan eksen başına `set_axis(HID_USAGE_X, …)` yoluna düşer.

---

## 7. Ayarlar — `app.py` başındaki blok

| Ayar | Varsayılan | Ne işe yarar |
|---|---|---|
| `HOST` / `PORT` | `127.0.0.1` / `5000` | adb reverse loopback'e düşürdüğü için 127.0.0.1 yeter. Wi-Fi'dan da erişmek istersen `0.0.0.0`. |
| `VJOY_DEVICE_ID` | `1` | vJoyConf'taki cihaz numarası |
| `US_MIN/MID/MAX` | `1000/1500/2000` | arayüzün ürettiği aralık |
| `REVERSE` | hepsi `False` | kanal başına ters çevirme |
| `MIRROR_RUDDER_TO_AILERON` | `False` | 3 kanal arayüz için |
| `FAILSAFE_MS` | `500` | bu süre paket gelmezse gaz kesilir |
| `USE_BATCH_UPDATE` | `True` | tek HID raporu / eksen başına SetAxis |

`HOST` ve `PORT` ortam değişkeninden de okunuyor: `SIM_HOST`, `SIM_PORT`,
`VJOY_ID`.

> **Ters yüzey?** Önce **simülatörün kendi kalibrasyonunu** dene. Orada
> çözülmüyorsa `REVERSE` sözlüğünü kullan. Sebebi: `REVERSE`'ü açarsan
> köprü artık uçakta olmayan bir davranış ekliyor demektir; test ettiğin
> şeyle uçtuğun şey ayrışır.

---

## 8. Sorun giderme

| Belirti | Sebep / çözüm |
|---|---|
| `pyvjoy bulunamadi` | `pip install pyvjoy` |
| `vJoyInterface.dll yuklenemedi` | 32/64-bit uyuşmazlığı. vJoy klasöründeki DLL'i `pyvjoy` paketinin içine kopyala. |
| `vJoy cihazi 1 alinamadi` | vJoyConf'ta cihaz kapalı, ya da başka bir program tutuyor. Simülatörü kapatıp `app.py`'yi önce başlat. |
| Telefonda sayfa açılmıyor | `adb reverse --list` boş mu? USB hata ayıklama açık mı? Kabloyu veri kablosuyla değiştir. |
| Sayfa açılıyor ama "kopuk" yazıyor | `app.py` çalışmıyor, ya da `SIM_URL` yanlış. Telefon tarayıcı konsolunu `chrome://inspect` ile aç. |
| Konsolda Hz görünüyor ama eksen kıpırdamıyor | vJoy tarafı. Adım 2'ye dön (vJoy Monitor). |
| vJoy Monitor'da kıpırdıyor ama simülatörde yok | RealFlight'ta kanal eşlemesi/kalibrasyon yapılmamış. Adım 4. |
| Uçak simülatörde durup duruyor donuyor | Failsafe tetikleniyor. Telefonun ekranı kilitleniyor olabilir — arayüzdeki Wake Lock devrede mi? |
| `code 400, Bad request syntax` | İstemci bağlantıyı sertçe kapattığında görülür, zararsız. |

---

## 9. Dosyalar

| | |
|---|---|
| [app.py](app.py) | Sunucu, eşleme, vJoy köprüsü, failsafe |
| [static/rc_sim_client.js](static/rc_sim_client.js) | Arayüze eklenecek istemci |
| [static/index.html](static/index.html) | 4 slider'lı test paneli |
| [tools/selftest.py](tools/selftest.py) | Uçtan uca test |
| [tools/fetch_client.py](tools/fetch_client.py) | socket.io.min.js indirici |
| [requirements.txt](requirements.txt) | Bağımlılıklar |

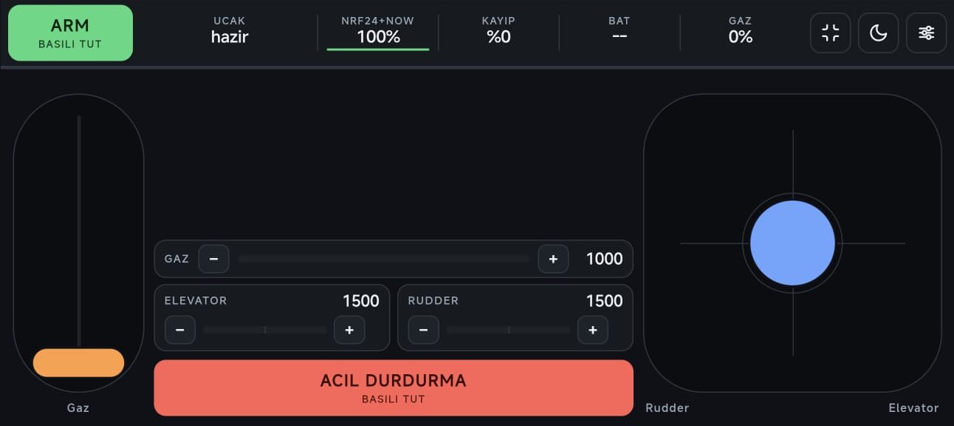
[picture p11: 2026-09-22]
docs/images/ui_3ch_dark.jpg

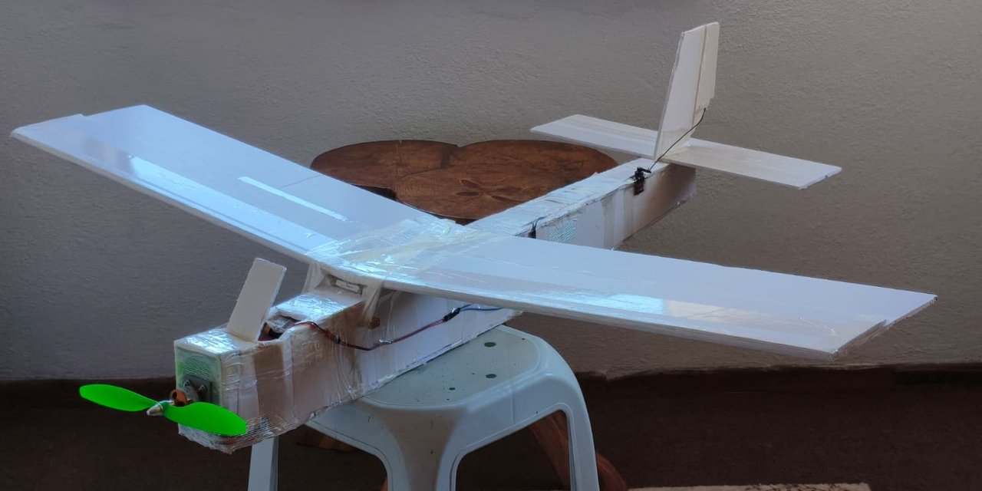
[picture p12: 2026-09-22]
docs/images/social_preview.jpg

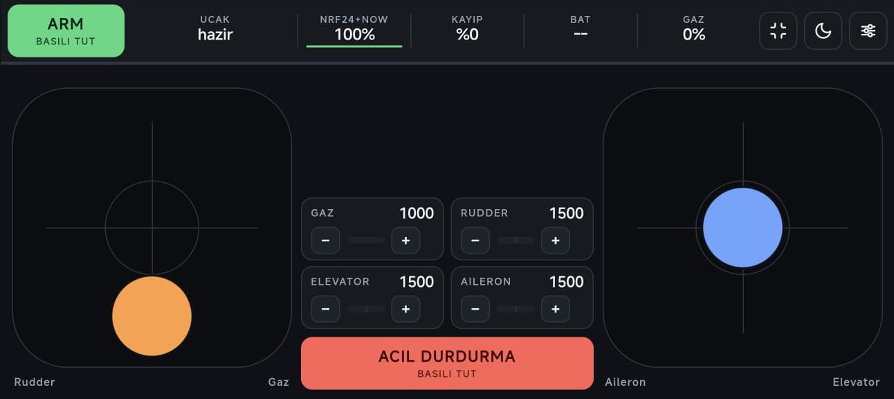
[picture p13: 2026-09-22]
docs/images/ui_4ch_dark.jpg

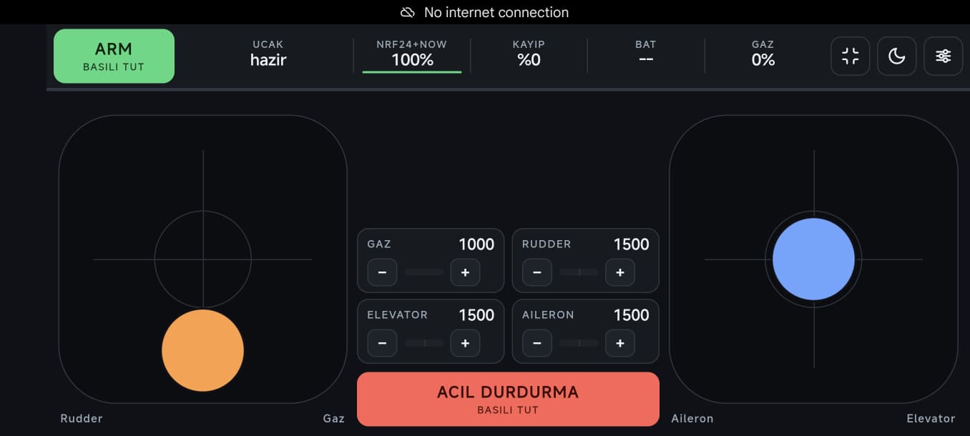
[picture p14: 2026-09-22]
firmware/4 kanal dark.jpeg

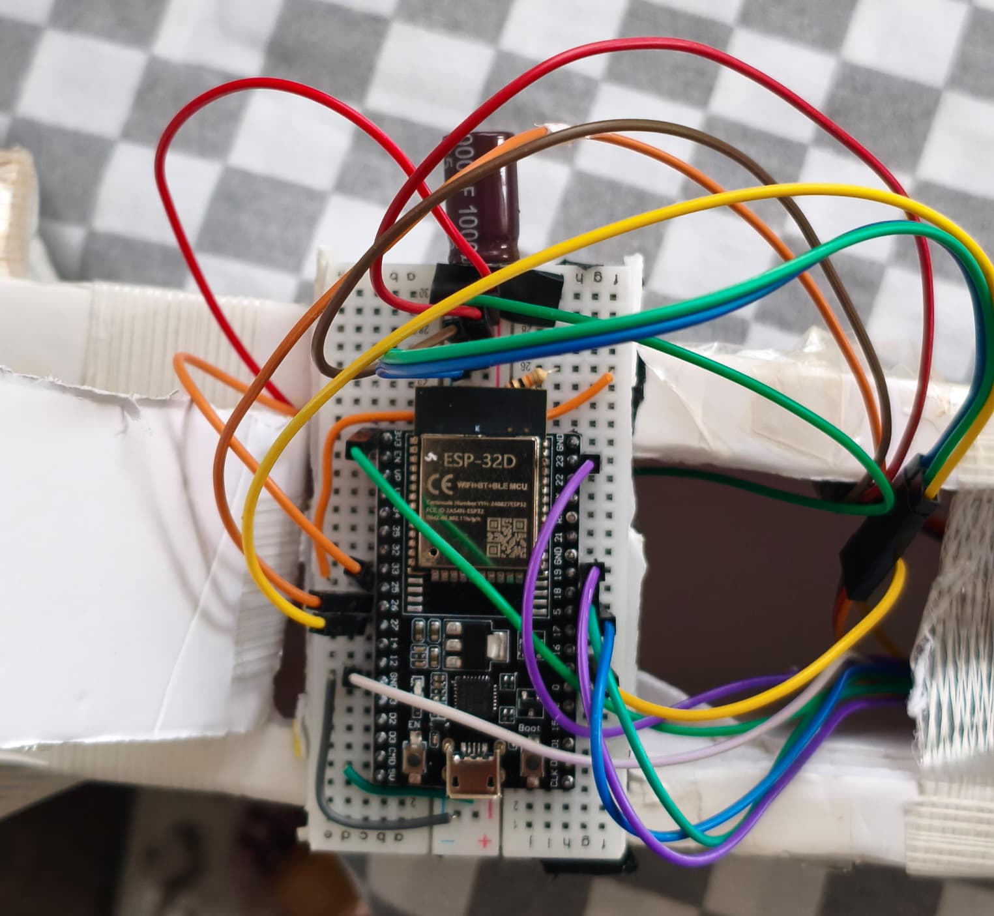
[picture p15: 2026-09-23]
avionics/esp32d_circuit.jpeg

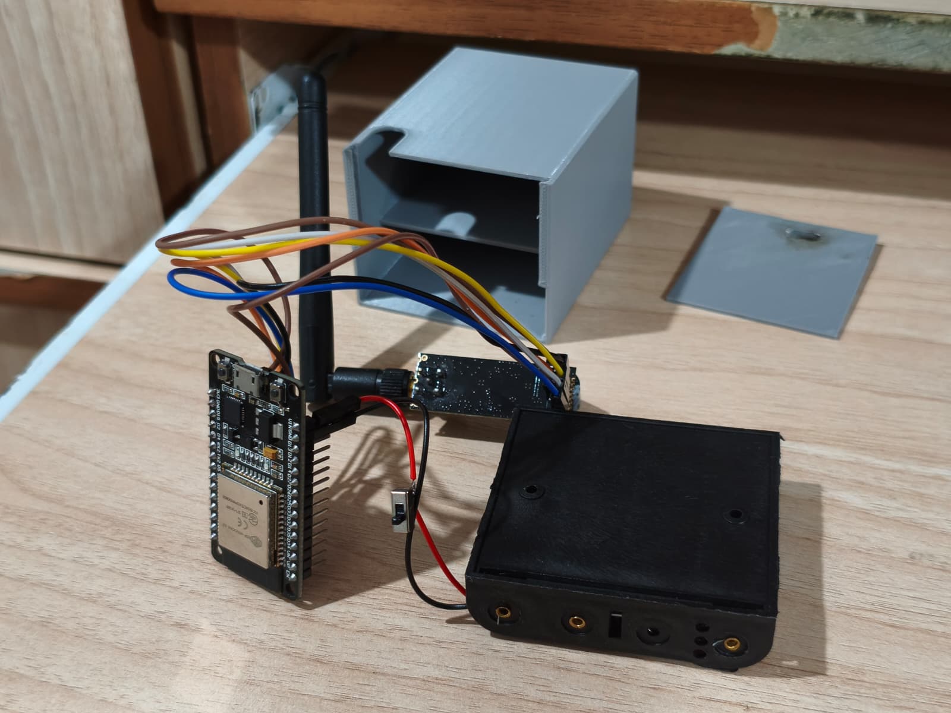
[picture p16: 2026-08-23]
avionics/ground_station_gateway_circuit_v1.jpeg

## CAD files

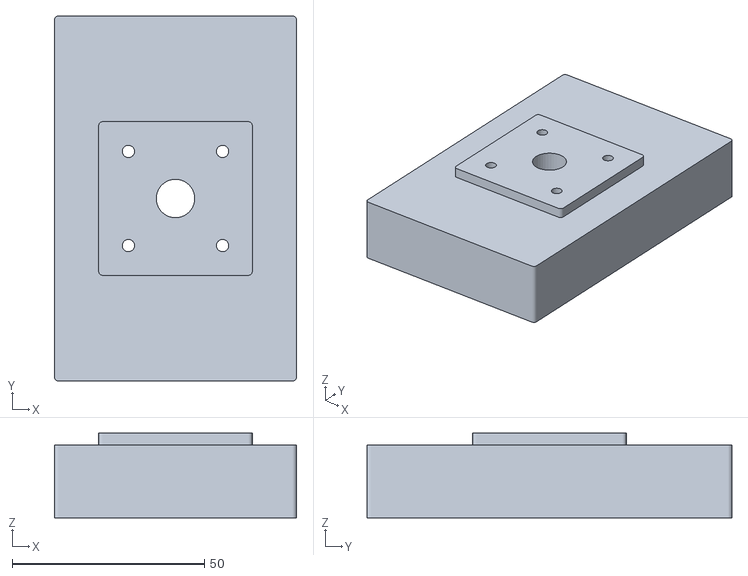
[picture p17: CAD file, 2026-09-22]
cad/print_files/Firewall.stl
63.0 x 95.0 x 22.0

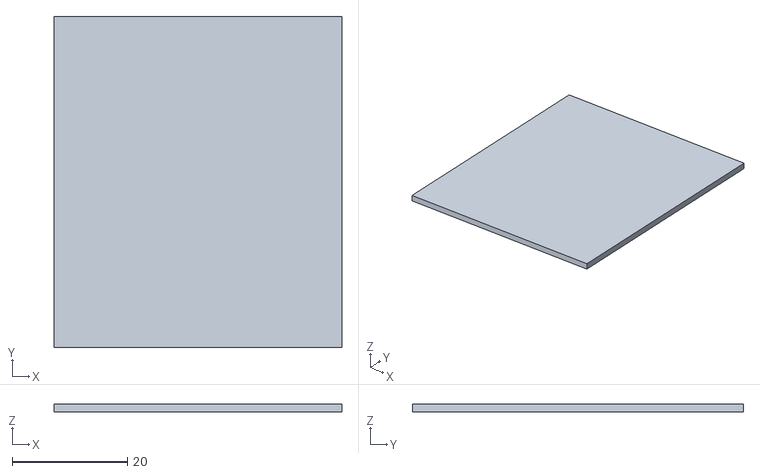
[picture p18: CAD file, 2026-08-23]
cad/print_files/Ground Station Housing Lid.stl
50.0 x 57.5 x 1.40

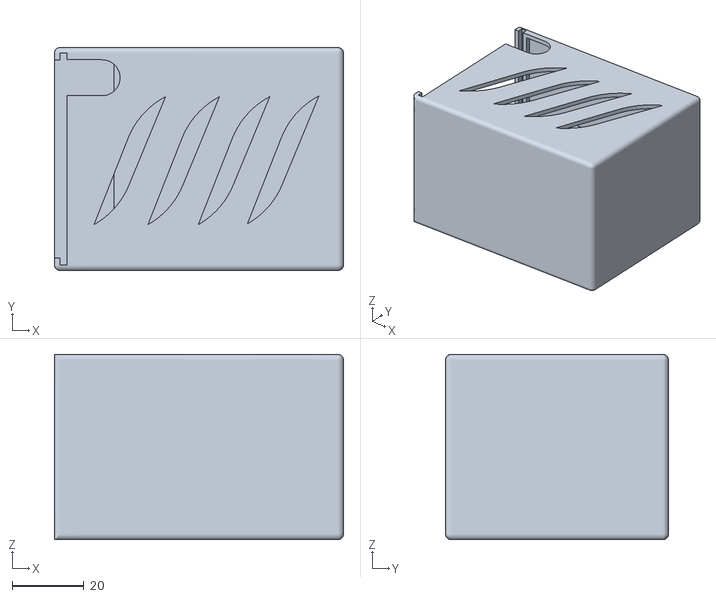
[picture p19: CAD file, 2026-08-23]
cad/print_files/Ground Station Housing.stl
80.4 x 62.0 x 51.5

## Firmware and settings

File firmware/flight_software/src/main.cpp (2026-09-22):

// ============================================================
// RC Plane - UCAK (alici) yazilimi          -- UCUSA HAZIR SURUM --
// Kart: ESP32 DevKitC 38 pin (ESP-WROOM-32 / 32D) + nRF24L01
// Kablolama: docs/kablolama.html
//
// UCAK 3 KANALLI: GAZ (ESC) + ELEVATOR + RUDDER.  Aileron YOK.
// Yatis rudder ile veriliyor (polihedral kanat, klasik 3 kanal duzeni).
//
// Ne yapar:
//   1. Kumandadan 50 Hz'de RcPacket dinler - nRF24 ve/veya ESP-NOW uzerinden
//   2. magic + CRC + protokol versiyonu dogrular
//   3. Kanallari kalibrasyon egrisinden gecirip LEDC ile mikrosaniye yazar
//   4. Kumandaya telemetri (paket kaybi, rxHz, durum) geri gonderir
//   5. RC_FAILSAFE_MS boyunca gecerli paket gelmezse failsafe'e duser
//   6. KALIBRASYON MODU: servo yon / notr / uc noktalari telsizden ayarlanip
//      NVS'e kaydedilir. Firmware yeniden derlenmez.
//
// GUVENLIK ZINCIRI:
//   - ARMED biti gelmedikce ESC her zaman stop darbesindedir.
//   - Gaz tavani ucak tarafinda AYRICA sinirlanir (kalibrasyondaki
//     "tavan" degeri). Kumandadaki sinira guvenilmez; iki taraf bagimsiz.
//   - Failsafe: gaz stop, yuzeyler KALIBRE EDILMIS notre, armed duser.
//   - Arm kilidi: boot'ta ve her failsafe'ten sonra takilir; kumandadan
//     ARMED=0 bir paket gorulmeden acilmaz. Yani link geri geldiginde
//     motor kendiliginden donmez.
//   - Kalibrasyon modunda ARM tamamen reddedilir, ESC stop'ta tutulur.
//   - Kalibrasyon uc noktalari RC_US_HARD_MIN..MAX ile kirpilir.
//
// UYARI: Tezgah denemelerinde PERVANE TAKILI OLMASIN!
// Kart ve servolar ayri bir UBEC'in 5V hattindan beslenir (hatta kondansator
// var), ESC'nin BEC'i kapali; GND'ler ortak olmali.
// ============================================================
// Uc cikisin hepsi cipin LEDC birimiyle surulur, ESP32Servo kullanilmaz:
//  - kutuphanenin pin izin listesi (GPIO 0'i reddediyor) devre disi kalir
//  - degerler dogrudan mikrosaniye yazilir, rc_protocol.h ile ayni dil
//  - derece <-> us donusumu olmadigi icin notr noktasi kaymaz

#include <Arduino.h>
#include <SPI.h>
#include <RF24.h>
#include <WiFi.h>
#include <esp_now.h>
#include <esp_wifi.h>
#include <Preferences.h>
#include "rc_protocol.h"

// ------------------------------------------------------------
// IKI TASIMA KATMANI (kumanda tarafiyla ayni olmali)
//
//   nRF24   - ayri modul, SPI, 2.508 GHz
//   ESP-NOW - cipin kendi WiFi radyosu, ek donanim YOK
//
// Ikisi de ayni RcPacket'i tasir ve ayni dogrulama/failsafe yolundan gecer.
// Hangisinden gelirse gelsin son gecerli paket kazanir; ikisi birlikte
// acikken yedekli link olur. nRF24 kablolamasi sorunluysa ucak yine ucar.
//
// ESP-NOW yayin adresi kullanir -> MAC eslestirmesi gerekmez. Tek sart:
// kumandanin AP_CHANNEL degeri ile asagidaki ESPNOW_CHANNEL ayni olmali.
// ------------------------------------------------------------
static const bool    USE_NRF24      = true;
static const bool    USE_ESPNOW     = true;
static const uint8_t ESPNOW_CHANNEL = 1;   // kumandadaki AP_CHANNEL ile ayni

// ------------------------------------------------------------
// KUMANDANIN AP'SINE ILISKILENME
//
// ESP-NOW bu topolojide TEK YONLU calisiyordu. Olcum:
//   kumanda -> ucak : 48 paket/s, %0 kayip        (calisiyor)
//   ucak -> kumanda : 58 cerceve/s gonderiliyor,
//                     gonderim geri cagrisi cb=58/fail0 (yani havaya cikiyor),
//                     kumanda nowrx=0/s goruyor     (hic gelmiyor)
// Iki taraf da kanal 1'de ve kumandanin alim geri cagrisi kayitli.
//
// Kalan tek asimetri: kumanda softAP isletiyor, ucagin STA'si hicbir yere
// ILISKILENMEMIS durumda. Iliskilendirilmemis bir istasyondan softAP'ye
// giden cerceveler guvenilir teslim edilmiyor - bu depoda daha once unicast
// telemetri de tam bu yuzden olmustu (ack=0/nack=57, bkz. dosya basindaki
// "kumandanin adresi" notu). O zaman cozum yayina gecmekti; yayin da ayni
// duvara carpiyor.
//
// Bu yuzden STA artik kumandanin AP'sine baglaniyor. Iliskilendirilmis
// istasyon <-> AP, Espressif'in en iyi destekledigi ESP-NOW topolojisi ve
// kanal uyusmasi kendiliginden garanti.
//
// Tasima YINE YAYIN: iliskilenme yalnizca topolojiyi simetrik yapmak icin.
// Baglanti kopsa bile ESP-NOW calismaya devam eder, yani kontrol
// iliskilenmeye BAGLI DEGIL - bu bir iyilestirme, bagimlilik degil.
// DENENDI, ISE YARAMADI - false birakildi.
//
// Iliskilenme hic kurulmadi (log: ap=yok) ve kumanda yine nowrx=0/s gordu.
// Yani ESP-NOW'in tek yonlu olmasi iliskilenme eksikligi DEGIL. Sebep hala
// bulunmadi; bu bayrak, denenmis ve elenmis bir yolun kaydi olarak duruyor.
// true yapmadan once kumandada AP_MAX_CONN >= 2 oldugunu dogrula.
static const bool    AP_BAGLAN = false;
static const char*   AP_SSID   = "RC-Plane-TX";
static const char*   AP_PASS   = "rcplane1234";

// ------------------------------------------------------------
// CIKIS PINLERI  --  ESP32 DevKitC 38 pin
//
// Kartin SOL pin sirasi ucus tarafi: ESC (25), elevator (26), rudder (27),
// GND ve 5V ayni sirada; telsiz kablolari sag sirada kaliyor.
//
// BESLEME: ayri UBEC (5V/3A). Cikisi kartin 5V pinine gelir, servolar oradan
// beslenir; hatta 5V-GND arasi kondansator var. ESC'nin lineer BEC'i kapali.
//
// ESC GPIO25'te, sinyal ile GND arasinda 10k var: boot sirasinda pin yuksek
// empedansta, pulldown sayesinde ESC cop darbe yerine HIC darbe gormez.
// C3'teki gibi GPIO0'a ALINMADI - klasik ESP32'de GPIO0 boot modu pini;
// uzerindeki pulldown karti her acilista yukleme moduna sokar, ucak acilmaz.
//
// Klasik ESP32'de kacinilan pinler:
//   0, 2, 12, 15  strapping (12 boot'ta yuksekse flash 1.8 V secilir)
//   14            boot sirasinda PWM cikarir, ESC'ye cop darbe gider
//   6-11          dahili flash - kartta D0-D3, CMD, CLK yazar ("D2" GPIO2 DEGIL)
//   1, 3          UART0, seri port
//   34-39         yalnizca giris
// ------------------------------------------------------------
static const int PIN_ESC      = 25;  // ESC sinyal (10k pulldown)
static const int PIN_ELEVATOR = 26;
static const int PIN_RUDDER   = 27;

// AILERON - 4 kanalli bir kanat takildiginda kullanilir.
// Su anki ucak aileronsuz; bu iki cikis bos duruyor ve notrde bekliyor,
// hicbir zarari yok. Kanat degistirildiginde tek yapilacak sey servolari
// takmak ve kumandada "Aileron var" secmek - firmware degismiyor.
static const int PIN_AIL_SOL  = 32;
static const int PIN_AIL_SAG  = 33;

// ------------------------------------------------------------
// nRF24L01 pinleri - kumandayla AYNI GPIO'lar
//   VCC  -> 3V3   ** 5V DEGIL **   (yanina 10 uF kondansator sart)
//                 38 pinli kartta 3V3 SOL UST pin; kablo karta alttan gecer
//   GND  -> GND   (sag sira, 19'un ustu)
//   SCK  -> GPIO18
//   MISO -> GPIO19
//   MOSI -> GPIO23
//   CSN  -> GPIO5
//   CE   -> GPIO4
//   IRQ  -> bagli degil
// 18/19/23 VSPI'nin kendi pinleri. GPIO5 strapping ama boot'ta yuksek
// cekilir, bu da CSN'nin istenen bosta hali; kumanda ayni pinde calisiyor.
// SPI.begin() cagrisinda pinler yine acikca verilir: once SPI'yi kapan bir
// kutuphane varsayilani degistirirse bile modul yerinde kalsin.
// ------------------------------------------------------------
static const uint8_t PIN_RF_SCK  = 18;
static const uint8_t PIN_RF_MISO = 19;
static const uint8_t PIN_RF_MOSI = 23;
static const uint8_t PIN_RF_CSN  = 5;
static const uint8_t PIN_RF_CE   = 4;

// SPI hizi. Kutuphane varsayilani 10 MHz; dupont kablo + lehimli tel ile bu hiz
// cogu zaman guvenilir degil, radio.begin() bazen geciyor bazen gecmiyor.
// Kumanda tarafi ayni sorunu yasayip 4 MHz'e dusmustu; ucak da ayni degeri
// kullansin ki iki taraf ayrisamasin.
static const uint32_t RF_SPI_HZ = 4000000;

// ------------------------------------------------------------
// Baglanti geri geldiginde failsafe'ten cikmak icin gereken ardisik
// gecerli paket sayisi. 50 Hz'de 10 paket ~ 200 ms saglam link demek.
// Tek pakette geri donmek, link segirdiginde motorun atim atim calismasina
// yol acar; bu histerezis onu engeller.
// ------------------------------------------------------------
static const uint8_t RELINK_PAKET = 10;

// nRF24 bulunamazsa bu araliklarla yeniden denenir. Boylece kabloyu
// duzeltmek icin karti resetlemek gerekmez; durum satiri kendiliginden
// BAGLI'ya doner. Ayni sekilde calisirken kablo cikarsa YOK'a duser.
static const uint32_t RF_RETRY_MS = 3000;

// ------------------------------------------------------------
// SAGIR MODUL KURTARMASI
//
// Olculen ariza: nRF24 bir sure calisiyor, sonra hicbir paket almamaya
// basliyor - ama isChipConnected() HALA gecerli cevap donduruyor (register
// okumasi dusuk akimla calisiyor, radyo kismi calismiyor). Yani radioOk true
// kaliyor ve RF_RETRY_MS'lik yeniden deneme yolu HIC devreye girmiyor: link
// karta reset atilana kadar kalici olarak olu kaliyor.
//
// Kosul hassas olmali, yoksa kumanda kapaliyken bosa donuyoruz: DIGER tasima
// yolundan paket AKIYORSA kumanda kesin yayin yapiyor demektir, dolayisiyla
// nRF24'un de bir sey duymasi gerekir. Duymuyorsa modul sagir -> tam yeniden
// kurulum (radio.begin() cipi bastan ayarlar).
static const uint32_t NRF_SAGIR_MS = 2000;

// ------------------------------------------------------------
// Telemetri tazeleme araligi.
//
// Telemetri sadece paket GELDIGINDE gonderilirse, kumandaya giden yol gelen
// yola bagimli hale gelir: iki yoldan ayni paket geldiginde ikincisi "tekrar"
// sayilip atlanir, link bir an segirdiginde de bosluk olusur. Kumanda 1 sn
// icinde taze telemetri gormezse ARM'i reddediyor, yani kucuk bosluklar bile
// "ucaktan cevap yok" demeye yetiyor.
//
// Bu yuzden telemetri paket gelisinden BAGIMSIZ olarak da tazelenir.
// 100 ms -> saniyede 10 tazeleme, kumandanin 1 sn'lik penceresinin 10 kati pay.
// ------------------------------------------------------------
static const uint32_t TLM_YENILE_MS = 100;

// ------------------------------------------------------------
// KALIBRASYON ZAMAN ASIMLARI
//
// TEST komutu servoyu bir uc noktaya surer. Operator slider'i birakip
// gittiginde servo orada takili kalirsa dayanaga dayanip akim ceker ve
// isinir - bu yuzden her TEST kendini bu sure sonunda notre birakir.
// Her yeni TEST komutu sayaci sifirlar, yani slider'i cevirirken servo
// istedigin noktada kalir.
// ------------------------------------------------------------
static const uint32_t KALIB_TEST_MS   = 4000;
static const uint32_t KALIB_SWEEP_MS  = 3000;   // bir tam min->max->min turu
static const uint8_t  KALIB_SWEEP_TUR = 3;      // kac tur sonra kendiliginden dursun
static const uint32_t KALIB_ESC_HI_MS = 30000;  // ESC kalibrasyonu 1. adim tavani

// ------------------------------------------------------------
// LEDC cozunurlugu
//
// 14 BIT. Klasik ESP32 20 bite kadar izin veriyor, ama bu firmware once
// ESP32-C3'te calisti ve C3'un LEDC zamanlayicisi en fazla 14 bit
// (soc_caps.h -> SOC_LEDC_TIMER_BIT_WIDE_NUM = 14). Orada 16 bit yazmak
// ledcSetup()'in sessizce 0 donmesine, pinde hic PWM olusmamasina yol
// aciyordu. 14 iki kartta da calisir; kart C3'e donerse sessizce bozulmasin
// diye 14'te kaliyor. Buraya 14'ten buyuk bir sayi YAZMA.
//
// 14 bit @ 50 Hz -> 16384 adim / 20000 us = ~1.22 us cozunurluk.
// Servo icin fazlasiyla yeterli (RC standardi 1 us adimlarla calisir).
// ------------------------------------------------------------
static const uint8_t  LEDC_BIT       = 14;
static const uint32_t LEDC_ADIM      = 1UL << LEDC_BIT;   // 16384
static const uint32_t PWM_PERIYOT_US = 20000;             // 50 Hz

// LEDC kanallari. Klasik ESP32'de 0..7 yuksek hiz grubu ve kanallar
// zamanlayiciyi CIFTLER halinde paylasir (0-1, 2-3, 4-5). Hepsi 50 Hz / 14 bit
// oldugu icin paylasim zararsiz. Farkli frekansli bir cikis eklenirse onu
// ayri bir cifte koy: ledcSetup() ortak zamanlayiciyi yeniden kurar ve
// komsu kanalin frekansi sessizce degisir.
static const int KANAL_ESC     = 0;
static const int KANAL_ELE     = 1;
static const int KANAL_RUD     = 2;
static const int KANAL_AIL_SOL = 3;
static const int KANAL_AIL_SAG = 4;   // kalibrasyon yuzeyi degil - sol'un aynasi

// RcSurface -> LEDC kanal / pin / isim tablolari. Kalibrasyon kodu
// yuzeyleri indeksle gezdigi icin bu tablolar tek dogruluk kaynagi.
static const int  SURF_KANAL[RC_SURF_COUNT] = { KANAL_ELE, KANAL_RUD, KANAL_ESC, KANAL_AIL_SOL };
static const int  SURF_PIN[RC_SURF_COUNT]   = { PIN_ELEVATOR, PIN_RUDDER, PIN_ESC, PIN_AIL_SOL };
static const char* SURF_AD[RC_SURF_COUNT]   = { "Elevator", "Rudder", "ESC/Gaz", "Aileron" };

// ============================================================
// KALICI AYARLAR (NVS)
//
// Servo yonu, notru ve uc noktalari artik derleme sabiti degil: kalibrasyon
// modundan ayarlanip flash'a yaziliyor. Kart resetlense de kalir, uctaki
// kartta USB olmadan da degistirilebilir.
// ============================================================
struct CikisAyar {
  uint16_t minUs;   // yuzey: alt uc      | gaz: ESC stop darbesi
  uint16_t midUs;   // yuzey: notr        | gaz: GAZ TAVANI
  uint16_t maxUs;   // yuzey: ust uc      | gaz: ESC tam gaz darbesi
  uint8_t  ters;    // yuzey: 1 = yon ters | gaz: kullanilmaz
};

static CikisAyar ayar[RC_SURF_COUNT];
static CikisAyar ayarKayitli[RC_SURF_COUNT];   // NVS'teki hali (kirli tespiti icin)

static Preferences nvs;
static const char* NVS_AD    = "rcplane";
static const char* NVS_ANAHT = "cfg";
// Yapinin duzeni degisirse eski kayit okunmamali. Bu imzayi struct'i her
// degistirdiginde artir; aksi halde flash'taki eski byte'lar yeni alanlara
// oturur ve servo ucus sirasinda anlamsiz bir yere gider.
static const uint32_t NVS_IMZA = 0x52435004;   // "RCP" + surum 4 (aileron eklendi)

static void ayarVarsayilan() {
  ayar[RC_SURF_ELEVATOR] = { RC_US_MIN, RC_US_MID, RC_US_MAX, 0 };
  ayar[RC_SURF_RUDDER]   = { RC_US_MIN, RC_US_MID, RC_US_MAX, 0 };
  // Gaz: stop 1000, tavan 2000 (sinirsiz), tam gaz 2000.
  // Ilk ucuslarda tavani arayuzden dusur - firmware degistirmeye gerek yok.
  ayar[RC_SURF_THROTTLE] = { RC_US_MIN, RC_US_MAX, RC_US_MAX, 0 };
  ayar[RC_SURF_AILERON]  = { RC_US_MIN, RC_US_MID, RC_US_MAX, 0 };
}

// Gelen bir ayarin makul olup olmadigina karar verir. Bozuk telsiz paketi,
// yanlis surum kumanda ya da elle girilmis sacma bir deger buradan gecemez.
static bool ayarGecerli(uint8_t surf, uint16_t mn, uint16_t md, uint16_t mx) {
  if (surf >= RC_SURF_COUNT) return false;
  if (mn < RC_US_HARD_MIN || mx > RC_US_HARD_MAX) return false;

  if (surf == RC_SURF_THROTTLE) {
    // minUs = stop, midUs = tavan, maxUs = tam gaz
    return mn <= 1200 && mx >= 1700 && md >= mn && md <= mx;
  }
  // Yuzey: siralama bozulmamali ve her iki yone en az 50 us hareket kalmali,
  // yoksa "kalibre ettim ama yuzey hic oynamiyor" durumu olusur.
  return mn + 50 <= md && md + 50 <= mx;
}

static bool ayarKirliMi() {
  for (uint8_t i = 0; i < RC_SURF_COUNT; i++) {
    if (ayar[i].minUs != ayarKayitli[i].minUs ||
        ayar[i].midUs != ayarKayitli[i].midUs ||
        ayar[i].maxUs != ayarKayitli[i].maxUs ||
        ayar[i].ters  != ayarKayitli[i].ters) return true;
  }
  return false;
}

// NVS'ten oku. Imza tutmuyorsa ya da icerik gecersizse varsayilana doner -
// bozuk bir flash kaydi ucagi asla anlamsiz bir servo konumuna surmez.
static bool ayarYukle() {
  struct { uint32_t imza; CikisAyar s[RC_SURF_COUNT]; } blok;
  nvs.begin(NVS_AD, true);
  const size_t n = nvs.getBytes(NVS_ANAHT, &blok, sizeof(blok));
  nvs.end();

  if (n != sizeof(blok) || blok.imza != NVS_IMZA) {
    ayarVarsayilan();
    memcpy(ayarKayitli, ayar, sizeof(ayar));
    return false;
  }
  for (uint8_t i = 0; i < RC_SURF_COUNT; i++) {
    if (!ayarGecerli(i, blok.s[i].minUs, blok.s[i].midUs, blok.s[i].maxUs)) {
      ayarVarsayilan();
      memcpy(ayarKayitli, ayar, sizeof(ayar));
      return false;
    }
  }
  memcpy(ayar, blok.s, sizeof(ayar));
  memcpy(ayarKayitli, ayar, sizeof(ayar));
  return true;
}
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
void loop() {
  radioReceive();     // nRF24
  espnowReceive();    // ESP-NOW
  kalibTick();        // kalibrasyon test/tarama zaman asimlari

  const uint32_t now = millis();

  // Kumanda sustuysa failsafe
  if (!failsafe && (now - lastRxMs > RC_FAILSAFE_MS)) {
    failsafe = true;
    failsafeUygula();
    Serial.println("[SAFE] FAILSAFE: paket yok, motor durdu, yuzeyler notr.");
  }

  // Telemetriyi paket gelisinden bagimsiz olarak tazele. Kumandanin ARM sarti
  // "1 sn icinde taze telemetri"; bu tazeleme olmadan tek bir paket boslugu
  // bile kumandanin "ucaktan cevap yok" demesine yol acabiliyor.
  //
  // Kalibrasyon modunda telemetri ile rapor SIRAYLA gonderilir: ayni geri
  // yol (ACK payload) ikisini de tasiyor, biri digerini ac birakmamali.
  static uint32_t lastTlmYenileMs = 0;
  static bool     raporSirasi     = false;
  static uint8_t  raporDonguSurf  = 0;
  if (now - lastTlmYenileMs >= (kalibModu ? TLM_YENILE_MS / 2 : TLM_YENILE_MS)) {
    lastTlmYenileMs = now;
    if (kalibModu && (raporSirasi = !raporSirasi)) {
      // Uc cikisi SIRAYLA raporla. Sadece son komut verilen cikisi
      // gondermek, kalibrasyon ekranindaki diger iki karti kumandanin
      // ayrica READ istemesine bagimli birakiyordu; boylece ekran
      // kendiliginden ve tam doluyor.
      raporGonder(raporDonguSurf);
      raporDonguSurf = (uint8_t)((raporDonguSurf + 1) % RC_SURF_COUNT);
    } else {
      // nRF24'ten bu pencerede paket geldi mi? Geldiyse kuyruk tuketiliyor
      // ve zaten taze; gelmediyse bayat yukleri atip yeniden doldur.
      if (nrfAlinan == nrfAlinanOnce) ackFifoTazele(lastSeq);
      else                            telemetriAckYukle(lastSeq);
      nrfAlinanOnce = nrfAlinan;
      telemetriYayinla(lastSeq);
    }
  }

  // nRF24 bulunamadiysa periyodik olarak yeniden dene. Kabloyu duzeltince
  // kart resetlemeye gerek kalmadan durum satiri BAGLI'ya doner.
  static uint32_t lastRfRetryMs = 0;
  if (USE_NRF24 && !radioOk && now - lastRfRetryMs >= RF_RETRY_MS) {
    lastRfRetryMs = now;
    radioSetup();
  }

  // SAGIR MODUL: radioOk true, cip SPI'dan cevap veriyor, ama radyo hicbir
  // sey duymuyor. Kumandanin yayin yaptigini DIGER yoldan gelen paketlerden
  // biliyoruz (lastRxMs taze), dolayisiyla nRF24 de duymali. Duymuyorsa
  // cipi bastan kur - yoksa link reset atilana kadar olu kalir.
  if (USE_NRF24 && radioOk && !failsafe &&
      now - lastRxMs   < RC_FAILSAFE_MS &&
      now - nrfSonRxMs > NRF_SAGIR_MS &&
      now - lastRfRetryMs >= RF_RETRY_MS) {
    lastRfRetryMs = now;
    nrfKurtarma++;
    Serial.printf("[RF] nRF24 SAGIR (%lu ms paket yok, kumanda yayinda) -"
                  " cip bastan kuruluyor.\n",
                  (unsigned long)(now - nrfSonRxMs));
    radioOk = false;        // radioSetup() bunu tekrar true yapacak
    radioSetup();
    nrfSonRxMs = now;       // kurtarmaya sans ver, hemen tekrar tetiklenmesin
  }

  // 1 sn'de bir paket kaybi + log
  if (now - lastStatMs >= 1000) {
    lastStatMs = now;

    // Surucunun O ANKI kanali. Calisirken kayarsa ESP-NOW sessizce tek yonlu
    // olur; boot'ta bir kez basmak bunu yakalamiyor.
    uint8_t nowKanal = 0;
    wifi_second_chan_t ikincilKanal = WIFI_SECOND_CHAN_NONE;
    if (espnowOk) esp_wifi_get_channel(&nowKanal, &ikincilKanal);
    // winAlinan sadece benzersiz paketleri sayiyor, yani her zaman
    // winBeklenen'den kucuk esit. Yine de tasmaya karsi acik korumali:
    // isaretsiz cikarma bir kez negatife duserse yuzde 255'e firlar.
    if (!winBeklenen)                  lossPct = 100;
    else if (winAlinan >= winBeklenen) lossPct = 0;
    else lossPct = (uint8_t)(100 - (uint32_t)winAlinan * 100 / winBeklenen);
    rxHz = (uint8_t)(winAlinan > 255 ? 255 : winAlinan);

    // Modulun O ANKI durumu. Calisirken kablo cikarsa bayragi dusur ki
    // yukaridaki yeniden deneme devreye girsin.
    const bool nrf = nrfBagli();
    if (radioOk && !nrf) {
      radioOk = false;
      nrfHataBasildi = false;   // kopus ayrintisi tekrar basilabilsin
      Serial.println("[RF] nRF24 BAGLI DEGIL - modul cevap vermeyi birakti.");
    }

    Serial.printf("[RX] nrf=%-11s now=%-6s | %s%s%s rxarm=%u kilit=%-5s relink=%u/%u | "
                  "thr=%u<-%u(%s) ele=%u->%u rud=%u->%u ail=%u->%u | %u paket, tekrar %u, "
                  "kayip %%%u, bozuk %u | tlm nrf=%u/red%u now=%u/hata%u "
                  "cb=%u/fail%u kanal=%u ap=%s kurt=%u %s\n",
                  !USE_NRF24 ? "KAPALI" : nrf ? "BAGLI" : "BAGLI-DEGIL",
                  !USE_ESPNOW ? "KAPALI" : espnowOk ? "BAGLI" : "YOK",
                  kalibModu ? "KALIBRASYON " : "",
                  failsafe ? "FAILSAFE " : "",
                  armed ? "ARMED " : "DISARM",
                  (unsigned)sonPaketArmed,
                  armKilidi ? "KAPALI" : "ACIK",
                  (unsigned)ardisikGecerli, (unsigned)RELINK_PAKET,
                  sonThr, sonThrIstek, sonThrSebep,
                  sonEle, sonCikis[RC_SURF_ELEVATOR],
                  sonRud, sonCikis[RC_SURF_RUDDER],
                  sonAil, sonCikis[RC_SURF_AILERON],
                  winAlinan, winTekrar, lossPct, winBozuk,
                  tlmNrf, tlmNrfRed, tlmNow, tlmNowHata,
                  nowCbOkHz, nowCbFailHz, (unsigned)nowKanal,
                  !AP_BAGLAN ? "kapali" : WiFi.status() == WL_CONNECTED ? "BAGLI" : "yok",
                  nrfKurtarma,
                  tlmNowHata ? esp_err_to_name(tlmSonHata) : "");

    winBeklenen = winAlinan = winBozuk = winTekrar = 0;
    tlmNrf = tlmNrfRed = tlmNow = tlmNowHata = 0;
    nowCbOkHz = nowCbOk;     nowCbOk   = 0;
    nowCbFailHz = nowCbFail; nowCbFail = 0;
    if (failsafe) {                     // baglanti koptuysa seq takibini sifirla
      seqBasladi = false;
      seqMaske   = 0;
    }
  }
}

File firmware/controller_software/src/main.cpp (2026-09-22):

// ============================================================
// RC Plane - KUMANDA (verici) yazilimi      -- UCUSA HAZIR SURUM --
// Kart: ESP32 DevKit (ESP-WROOM-32) + nRF24L01
//
// UCAK 3 KANALLI: GAZ (ESC) + ELEVATOR + RUDDER.  Aileron YOK.
//
// Ne yapar:
//   1. WiFi erisim noktasi acar  -> SSID: RC-Plane-TX
//   2. 192.168.4.1 adresinde gercek kumanda gorunumlu arayuz sunar:
//      iki gimbal (kol yuvasi), trim, expo/dual-rate, kalkis oncesi kontrol
//   3. Kol konumlarini expo/oran/trim'den gecirip 50 Hz'de ucaga gonderir
//   4. Ucaktan telemetri okur ve arayuzde gosterir
//   5. Servo kalibrasyon komutlarini ucaga iletir ve raporlari geri okur
//
// TASIMA: kol verisi WebSocket (port 81) uzerinden gelir. WebServer'in
// her cevaba "Connection: close" koymasi 20 Hz'de gecikmeyi dalgalandiriyor;
// WebSocket'te baglanti bir kez kuruluyor. Tarayici WebSocket kuramazsa
// otomatik olarak /c HTTP yoluna duser - iki yol da her zaman acik.
//
// GUVENLIK ZINCIRI:
//   - ARM icin gaz kolu minimumda olmali.
//   - ARM icin ucaktan TAZE TELEMETRI gelmeli. Ucak cevap vermiyorsa
//     arayuz ARMED gostermez; "arm ettim ama ucak duymadi" olusamaz.
//   - Ucaktan 1 sn telemetri gelmezse otomatik DISARM.
//   - Tarayici 1 sn komut gondermezse otomatik DISARM.
//   - Ucak kalibrasyon modundayken ARM reddedilir.
//   - Gaz tavani hem burada (kol siniri) hem ucakta (bagimsiz tavan) var.
//
// KUMANDA DURUMU != UCAK DURUMU. Ikisi arayuzde ayri gosterilir. Ucak,
// boot'ta ve her failsafe'ten sonra arm kilitli gelir: kumandadan ARMED=0
// bir paket gormeden arm olmaz. Bu yuzden kumanda "ARMED" derken ucak
// "DISARM" diyebilir; o zaman DISARM'a basip tekrar ARM etmek gerekir.
// ============================================================

#include <Arduino.h>
#include <SPI.h>
#include <RF24.h>
#include <WiFi.h>
#include <WebServer.h>
#include <esp_now.h>
#include <esp_wifi.h>
#include <Preferences.h>
#include "rc_protocol.h"
#include "mini_ws.h"
#include "web_ui.h"

// ------------------------------------------------------------
// IKI TASIMA KATMANI
//
// Ayni RcPacket iki yoldan da gidebilir:
//   nRF24  - ayri modul, SPI, 2.508 GHz
//   ESP-NOW- kartin kendi WiFi radyosu, ek donanim YOK
//
// ESP-NOW yayin (broadcast) adresi kullanir, yani iki kartin MAC adresini
// birbirine tanitmak gerekmez - ac ve calisir. nRF24 kablolamasi/modulu
// sorunluysa sistem yine ucar; ikisi birlikte aciksa yedekli link olur.
//
// Ucak tarafinda da ayni iki katman acik olmali (flight_software).
// ------------------------------------------------------------
static const bool USE_NRF24  = true;
static const bool USE_ESPNOW = true;

// ------------------------------------------------------------
// nRF24L01 pinleri - semadaki baglanti
//   VCC  -> 3V3    (kirmizi)   ** 5V DEGIL **
//   GND  -> GND    (siyah)
//   CE   -> GPIO4  (mavi)
//   CSN  -> GPIO5  (magenta)
//   SCK  -> GPIO18 (turuncu)
//   MOSI -> GPIO23 (camgobegi)
//   MISO -> GPIO19 (yesil)
//   IRQ  -> bagli degil (kullanilmiyor)
//
// nRF24 konnektoru 2x4'tur ve 1. bacak GND, 2. bacak VCC'dir. Konnektoru bir
// sira kaydirmak cok kolay ve VCC/GND ters gelirse modul yanar - taktiktan
// sonra module dokun, ilikse hemen cek.
//
// VCC-GND arasina 10-100uF kondansator SART. Modul yayin aninda akim tepesi
// cekiyor; kartin 3V3 regulatoru bunu karsilamazsa modul brown-out olur ve
// radio.begin() bazen gecer bazen gecmez.
// ------------------------------------------------------------
static const uint8_t PIN_CE   = 4;
static const uint8_t PIN_CSN  = 5;
static const uint8_t PIN_SCK  = 18;
static const uint8_t PIN_MISO = 19;
static const uint8_t PIN_MOSI = 23;

// SPI hizi. Kutuphane varsayilani 10 MHz; dupont kablo + breadboard ile
// bu hiz cogu zaman guvenilir degil. 4 MHz her kurulumda sorunsuz calisir.
// Hangi hizin saglam oldugunu ogrenmek icin: pio run -e rfdiag -t upload -t monitor
static const uint32_t RF_SPI_HZ = 4000000;

// ------------------------------------------------------------
// TEZGAH MODU  --  UCUSTA false OLMALI
//
// Normalde ARM icin ucaktan TAZE TELEMETRI sart. Bu, "kumandada ARMED
// yaziyor ama ucak komutu hic duymadi" durumunu imkansiz kilan kilit.
// Tezgahta telemetri yolu bozukken (ornegin ucagin 3.3V hatti yayin
// aninda cokuyorken) bu kilit ARM etmeyi tamamen engelliyor.
//
// true iken:
//   - ARM, telemetri olmadan da kabul edilir
//   - "telemetri yok" gerekcesiyle otomatik DISARM devre disi kalir
// Degismeyenler: gaz kolu minimumda olma sarti, gaz siniri, web watchdog,
// ucak tarafindaki arm kilidi ve failsafe. Yani motor yine de ancak ucak
// paketleri gercekten aliyorsa doner.
//
// PERVANE TAKILIYKEN VEYA UCUSTA ASLA true BIRAKMA. Acikken hem boot
// logunda hem her saniye [TX] satirinda hem de web arayuzunde uyari cikar.
// ------------------------------------------------------------
static const bool TEZGAH_MODU = false;

// ------------------------------------------------------------
// WiFi erisim noktasi
// AP kanali 1 = 2.412 GHz, nRF24 kanali 108 = 2.508 GHz. Aralarinda 96 MHz
// var, yani WiFi trafigi telsiz linkini bozmuyor. RC_RF_CHANNEL'i
// degistirirsen bu kanali da gozden gecir - ust uste binmemeliler.
// ------------------------------------------------------------
static const char*   AP_SSID     = "RC-Plane-TX";
static const char*   AP_PASS     = "rcplane1234";  // en az 8 karakter
static const uint8_t AP_CHANNEL  = 1;
// TEK istemci: yalnizca telefon.
//
// Bir ara 2 yapilmisti (ucagin AP'ye iliskilenmesi denenecekti); o deneme
// ise yaramadi ve geri alindi (bkz. ucak tarafindaki AP_BAGLAN notu), yani
// ikinci yuva gereksiz kaldi.
//
// Ve zararsiz degil: mini_ws TEK WebSocket istemcisi destekliyor, yeni gelen
// eskisini atiyor. Ikinci bir cihaz (ya da ikinci bir sekme) baglanirsa iki
// taraf birbirini atip duruyor, her kopusta web watchdog devreye girip GAZI
// KESIYOR. Yuvayi 1'de tutmak bu yarisi bastan engelliyor.
static const uint8_t AP_MAX_CONN = 1;              // sadece telefon
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

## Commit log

2026-08-11 alınacak malzemeler listesi güncellendi
    [Alinacak Malzemeler Ucuz.xlsx]
2026-08-12 malzemeler güncellendi
    [Alinacak Malzemeler Ucuz.xlsx]
2026-08-23 proje yapisi duzenlendi: firmware, avionics, cad ve dokumanlar tek repoda
    - ust dizindeki Avionics/, Mechanics/ ve Flight Software/ iceriklerini repoya tasi
    - avionics/ : ucus ve yer istasyonu devre fotograflari
    - cad/ : yer istasyonu kutusu icin baskiya hazir STL'ler
    - firmware/ : flight_software (ESP32-C3 alici) + controller_software (ESP32 verici)
    - RF_PROTOKOL.md -> docs/RF_PROTOCOL.md
    - ucak tarafi pin tablosu gercek kablolamayla dolduruldu
    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
    [Alinacak Malzemeler Ucuz.xlsx, Alınacak Malzemeler.xlsx, Ground Station Housing Lid.stl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]
2026-09-22 Add tests for UI elements and functionality in firmware tools
    - Implemented `test_ids.py` to verify the existence of IDs in HTML against JavaScript references, ensuring no missing elements that could cause runtime errors.
    - Created `test_stick.mjs` to validate the kinematics of the control stick, ensuring the expected behavior of the stick's movement and its interaction with the UI.
    - Developed `test_theme.py` to measure the contrast ratios of UI elements against WCAG standards for both light and dark themes, ensuring accessibility compliance.
    - Added `test_throttle.mjs` to compare the output of the `gazCikisi()` function in the UI with the corresponding C++ implementation in `main.cpp`, ens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
    [Firewall.stl]
2026-09-22 Update firmware documentation and code to reflect separate UBEC power supply
    - Updated AGENTS.md and README.md to clarify the use of a separate 5V/3A UBEC for powering the board and servos, disabling the ESC's BEC.
    - Revised kablolama.html to accurately describe the power connections and added details about the UBEC.
    - Adjusted comments in servo_bench_ledc.cpp and main.cpp to reflect the new power supply setup.
    - Modified platformio.ini comments to indicate the use of UBEC instead of ESC's BEC.
    - Added new image files for firmware documentation.
2026-09-25 Add flight performance chart generation to diagrams
    - Introduced a new function `performance()` to generate SVG charts for flight performance based on static thrust values.
    - Updated the `svg()` function to accept additional styles for better customization.
    - Implemented detailed performance metrics including thrust vs drag and simulated hand launch scenarios.
    - Added a new SVG output for flight performance alongside existing diagrams.
